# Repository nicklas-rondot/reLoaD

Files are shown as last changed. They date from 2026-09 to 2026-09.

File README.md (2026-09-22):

# *reLoaD* framework

The *reLoaD* (reconfigurable Lab on a Disc) framework is an open-hardware centrifugal microfluidics framework for research, teaching and application. It consists of three core modules:

1. The *Motor* module:
  Consists of a consumer-grade brushless DC (BLDC) motor driven by a PCB with a microcontroller, three-phase half bridge and magnetic encoder using field-oriented-control (FOC). This enables both high-speed rotation for centrifugal microfluidic operations and precise angular positioning for sensor alignment.
2. The *Base* module:
  A stationary PCB with a microcontroller that serves as a platform to mount/control stationary sensors and actuators. Furthermore, it integrates wireless power transmission electronics.
3. The *Spinnner* module:
  A PCB co-rotating with the microfluidic disc with a microcontroller that serves as a platform to mount/control co-rotating sensors and actuators (primarily heaters). It integrates rectification and power regulation electronics for wirelessly receiving power from the *Base* module.

All modules are based on the ESP32-S3 microcontroller. Sensors and actuators can be placed on *Shields*, PCBs that mount to the Base and Spinner modules using standard pin headers. It is advantageous to place optical sensors and actuators on a *Base Shield*, as this allows using the rotation of the microfluidic disc to align multiple chambers with a single sensor one after another. Moreover, it is recommended to place sensors and actuators that need to be in direct contact with the microfluidic disc on the *Spinner Shield*, since this enables interaction with the disc during rotation and necessitates no movable components. The control software is available at github.com/nicklas-rondot/reLoaD-control

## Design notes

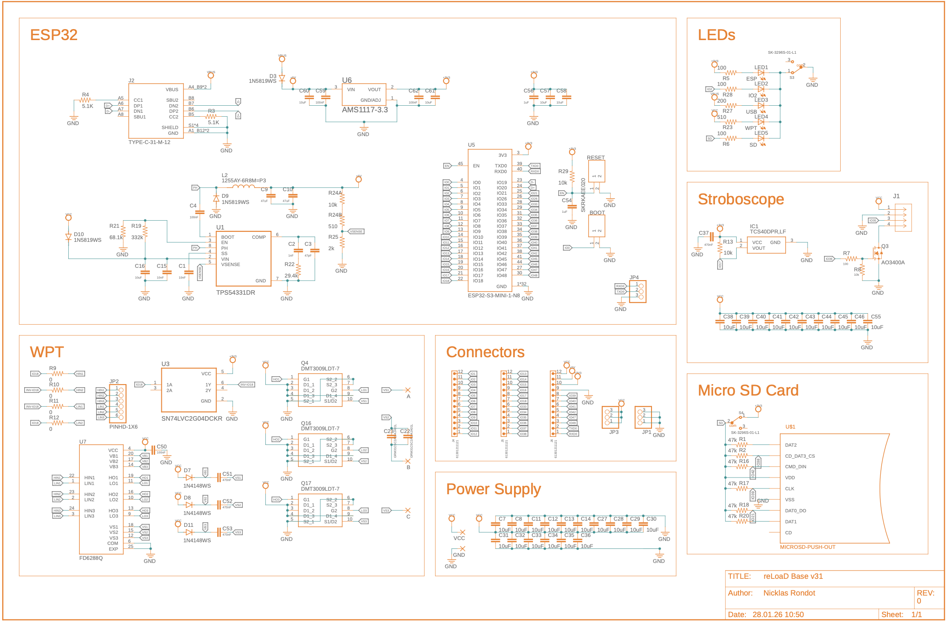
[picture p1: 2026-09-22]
Base/hardware/Base Schematic.png

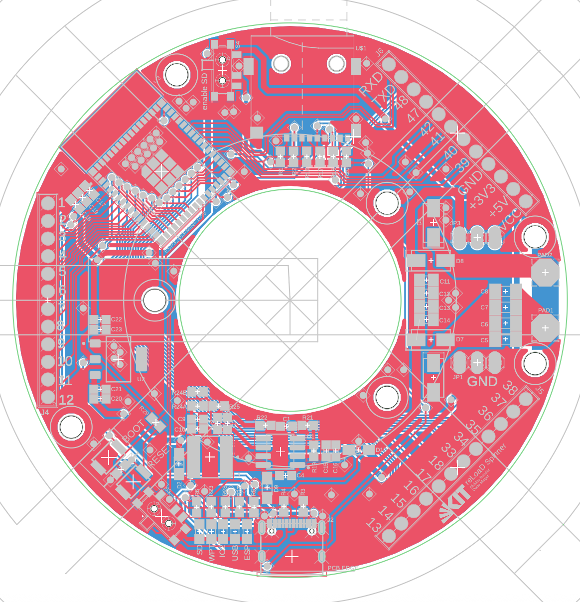
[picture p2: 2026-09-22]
Spinner/hardware/Spinner PCB.png

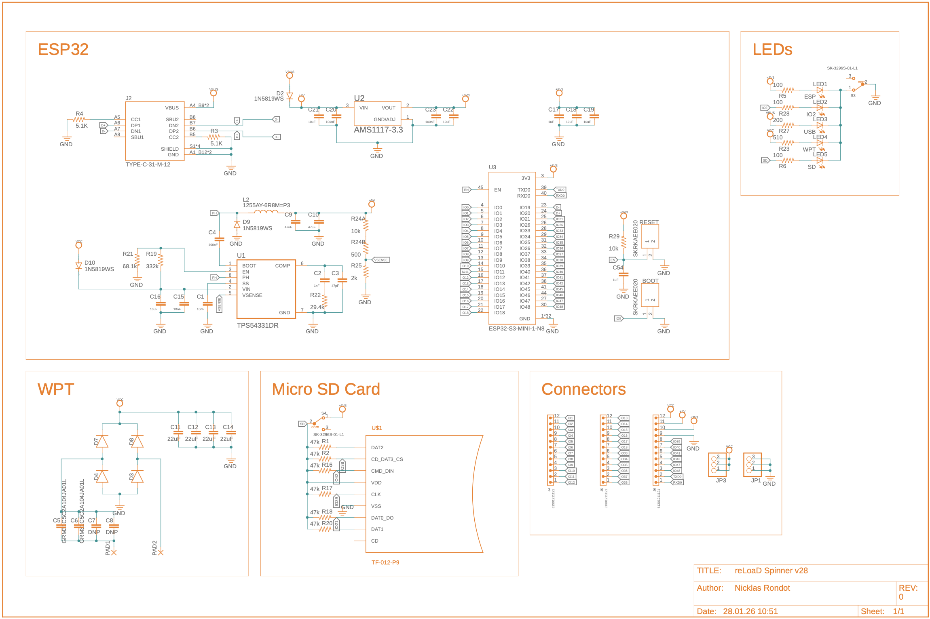
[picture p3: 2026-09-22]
Spinner/hardware/Spinner Schematic.png

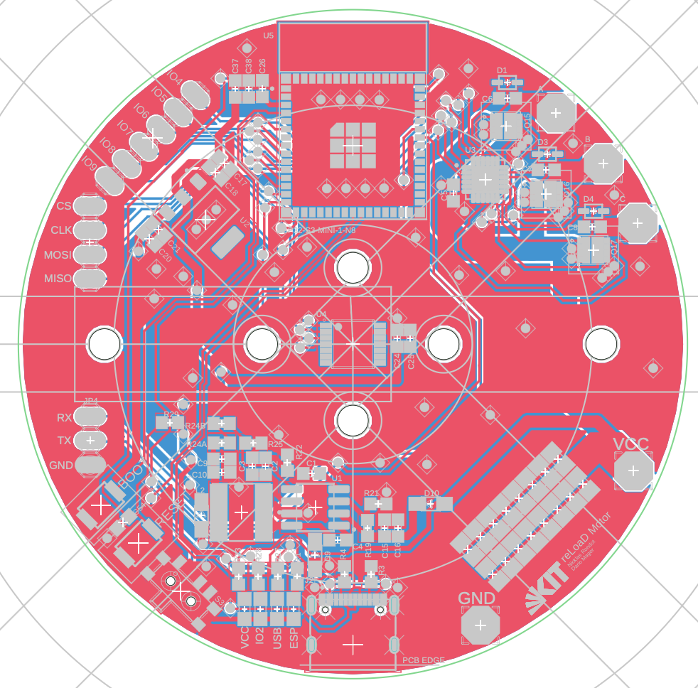
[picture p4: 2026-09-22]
Motor/hardware/Motor PCB.png

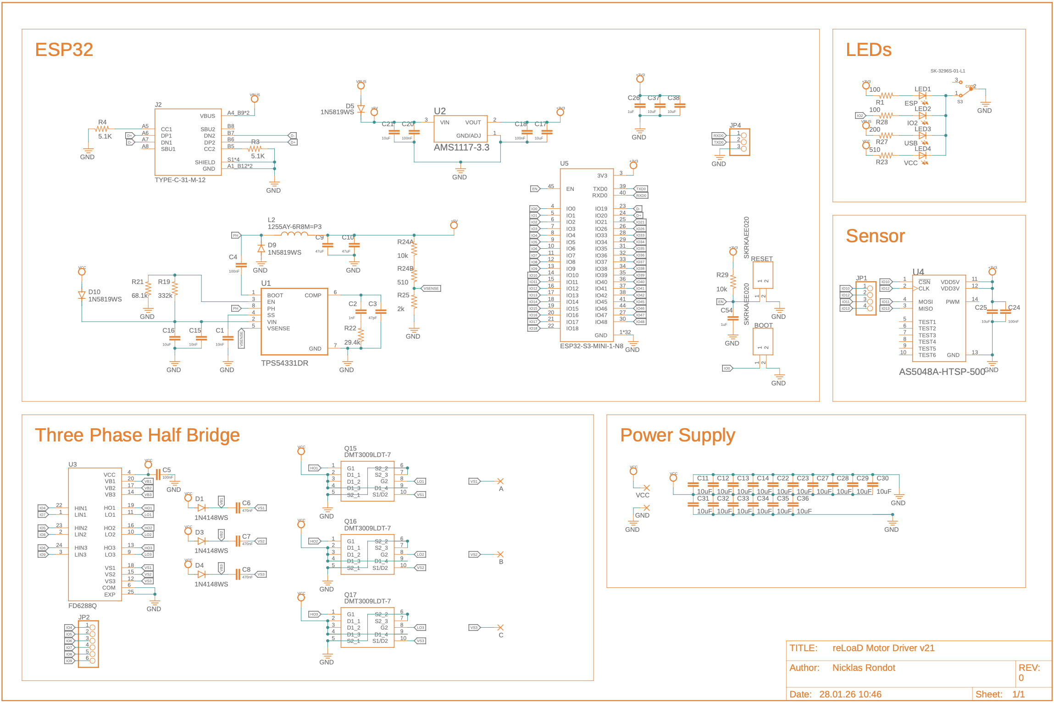
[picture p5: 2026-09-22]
Motor/hardware/Motor Schematic.png

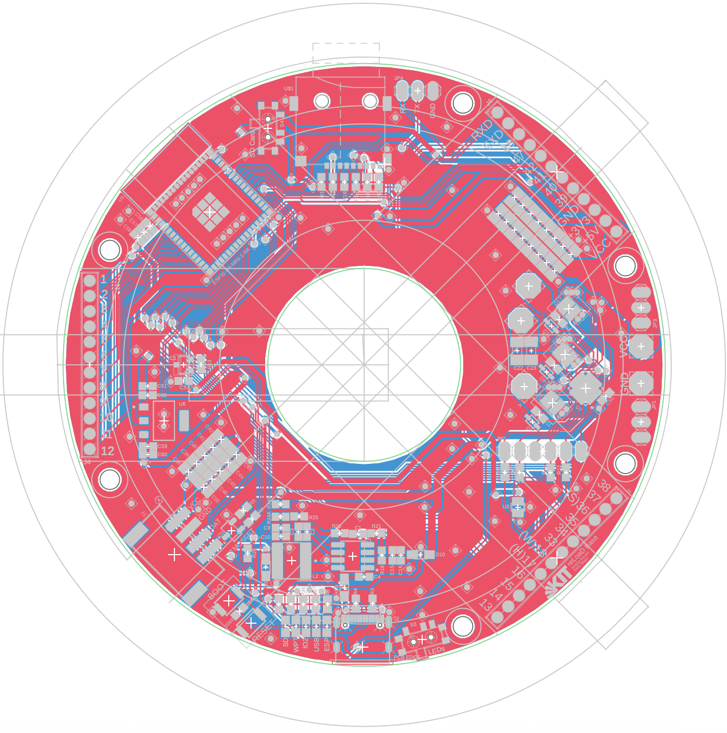
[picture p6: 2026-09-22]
Base/hardware/Base PCB.png

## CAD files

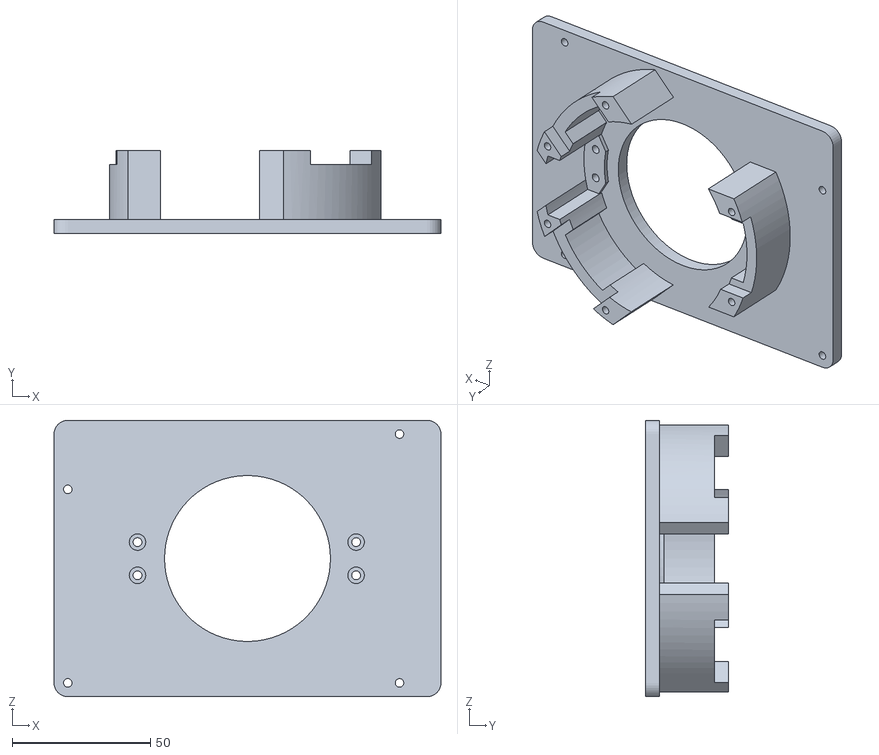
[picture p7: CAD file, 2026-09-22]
assembly/reLoaD Base Mount.stl
140.0 x 30.0 x 100.0

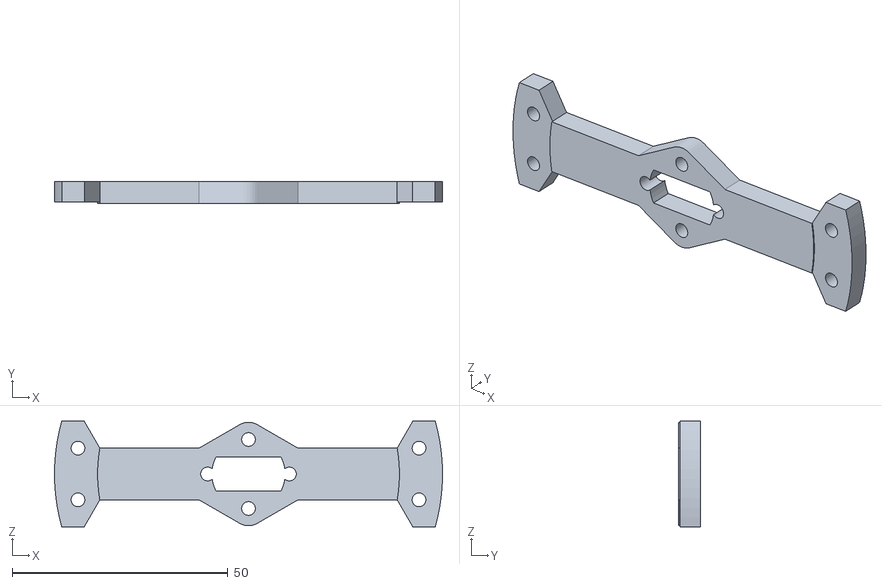
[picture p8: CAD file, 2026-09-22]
assembly/reLoaD Motor Mount high version.stl
90.0 x 5.00 x 24.5

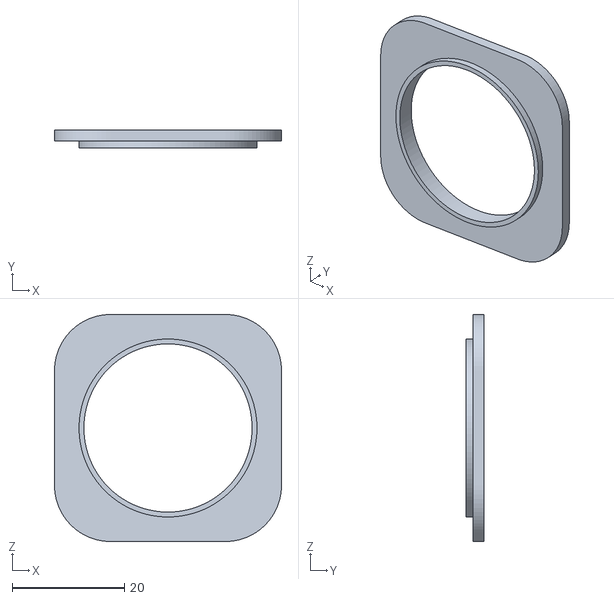
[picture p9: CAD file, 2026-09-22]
assembly/reLoaD Coil lifter v2.stl
40.5 x 3.25 x 40.5

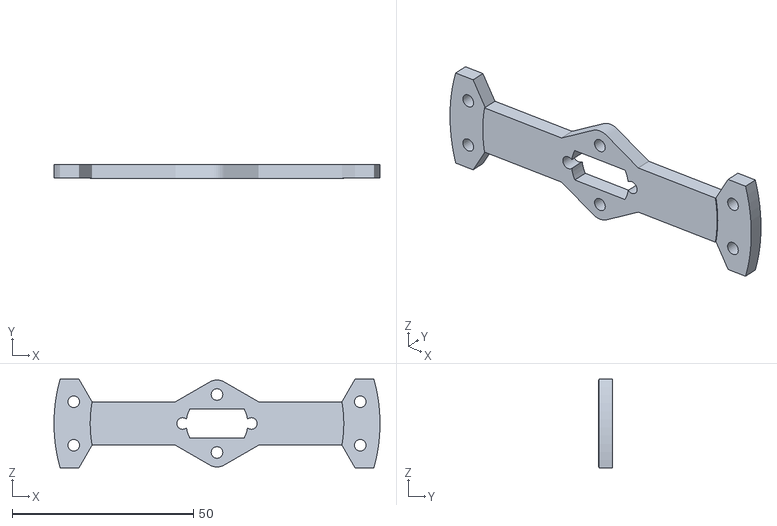
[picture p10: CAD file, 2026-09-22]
assembly/reLoaD Motor Mount.stl
90.0 x 4.00 x 24.5

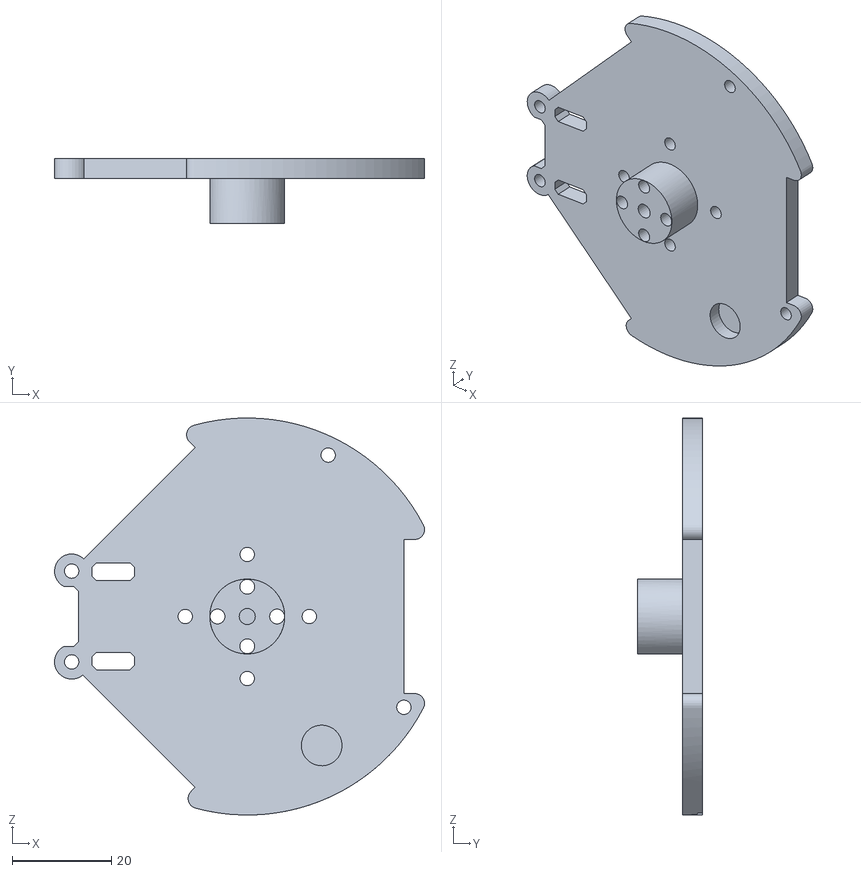
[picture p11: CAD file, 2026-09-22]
assembly/reLoaD Spinner Mount v3.stl
74.6 x 13.0 x 80.0

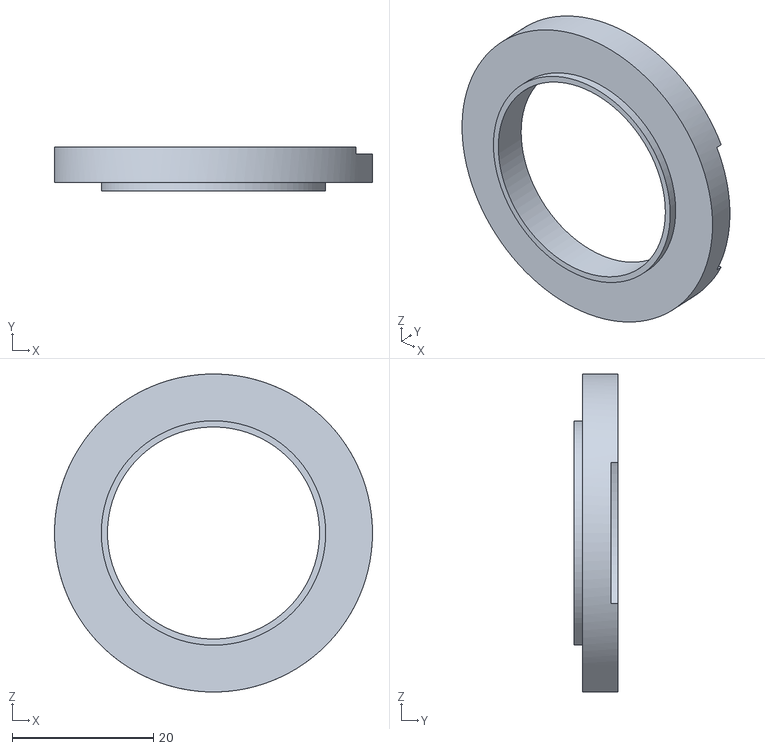
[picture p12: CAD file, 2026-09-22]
assembly/reLoaD Coil lifter.stl
45.0 x 6.25 x 45.0

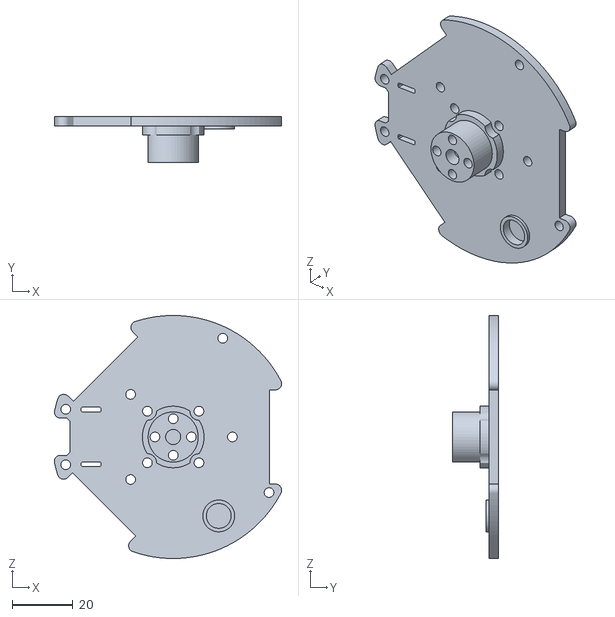
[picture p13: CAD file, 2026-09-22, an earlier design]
assembly/reLoaD Spinner Mount v2.stl
74.9 x 15.0 x 80.0

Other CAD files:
assembly/reLoaD assembly.step

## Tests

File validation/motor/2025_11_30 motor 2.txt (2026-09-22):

11:09:17.006	RPM Sensor Ready (Adaptive Mode)...
RPM:0

11:09:21.838	RPM:12.40

11:09:22.438	RPM:100.68

11:09:22.572	RPM:439.07

11:09:22.692	RPM:480.92

11:09:22.812	RPM:516.97

11:09:22.932	RPM:548.59

11:09:23.037	RPM:576.83

11:09:23.127	RPM:602.31

11:09:23.217	RPM:625.52

11:09:23.322	RPM:646.75

11:09:23.412	RPM:666.37

11:09:23.487	RPM:684.65

11:09:23.577	RPM:701.69

11:09:23.667	RPM:717.77

11:09:23.742	RPM:732.71

11:09:23.831	RPM:746.83

11:09:23.907	RPM:760.03

11:09:23.981	RPM:772.44

11:09:24.056	RPM:784.27

11:09:24.131	RPM:795.50

11:09:24.206	RPM:806.28

11:09:24.282	RPM:816.37

11:09:24.356	RPM:826.13

11:09:24.432	RPM:835.38

11:09:24.492	RPM:844.12

11:09:24.567	RPM:852.47

11:09:24.642	RPM:860.49

11:09:24.702	RPM:868.11

11:09:24.776	RPM:875.25

11:09:24.852	RPM:882.20

11:09:24.910	RPM:888.84

11:09:24.987	RPM:895.09

11:09:25.047	RPM:900.96

11:09:25.107	RPM:906.51

11:09:25.182	RPM:911.69

11:09:25.241	RPM:916.53

11:09:25.302	RPM:921.09

11:09:25.376	RPM:925.41

11:09:25.437	RPM:929.48

11:09:25.496	RPM:933.30

11:09:25.571	RPM:937.03

11:09:25.630	RPM:940.38

11:09:25.692	RPM:943.57

11:09:25.752	RPM:946.43

11:09:25.827	RPM:949.25

11:09:25.887	RPM:951.78

11:09:25.947	RPM:954.26

11:09:26.006	RPM:956.75

11:09:26.066	RPM:958.90

11:09:26.142	RPM:960.98

11:09:26.202	RPM:962.90

11:09:26.261	RPM:964.69

11:09:26.322	RPM:966.37

11:09:26.381	RPM:967.99

11:09:26.442	RPM:969.37

11:09:26.502	RPM:970.81

11:09:26.561	RPM:972.20

11:09:26.636	RPM:973.52

11:09:26.697	RPM:974.72

11:09:26.756	RPM:975.86

11:09:26.817	RPM:976.94

11:09:26.877	RPM:977.84

11:09:26.937	RPM:978.86

11:09:26.996	RPM:979.69

11:09:27.056	RPM:980.58

11:09:27.117	RPM:981.55

11:09:27.177	RPM:982.45

11:09:27.236	RPM:983.16

11:09:27.297	RPM:983.93

11:09:27.371	RPM:984.58

11:09:27.431	RPM:985.35

11:09:27.492	RPM:985.80

11:09:27.552	RPM:986.52

11:09:27.611	RPM:987.23

11:09:27.671	RPM:987.82

11:09:27.731	RPM:988.34

11:09:27.792	RPM:988.86

11:09:27.851	RPM:989.25

11:09:27.912	RPM:989.71

11:09:27.971	RPM:990.10

11:09:28.031	RPM:990.36

11:09:28.092	RPM:990.82

11:09:28.151	RPM:991.21

11:09:28.211	RPM:991.54

11:09:28.271	RPM:992.00

11:09:28.331	RPM:992.33

11:09:28.392	RPM:992.52

11:09:28.452	RPM:992.85

11:09:28.512	RPM:992.98

11:09:28.570	RPM:993.31

11:09:28.631	RPM:993.57

11:09:28.691	RPM:993.90

11:09:28.751	RPM:994.17

11:09:28.811	RPM:994.43

11:09:28.887	RPM:994.69

11:09:28.931	RPM:994.83

11:09:28.992	RPM:994.96

11:09:29.067	RPM:995.22

11:09:29.112	RPM:995.49

11:09:29.187	RPM:995.69

11:09:29.247	RPM:996.02

11:09:29.306	RPM:996.15

11:09:29.366	RPM:996.41

11:09:29.427	RPM:996.41

11:09:29.487	RPM:996.55

11:09:29.546	RPM:996.68

11:09:29.606	RPM:996.74

11:09:29.666	RPM:996.94

11:09:29.726	RPM:997.08

11:09:29.786	RPM:997.14

11:09:29.846	RPM:997.34

11:09:29.906	RPM:997.47

11:09:29.966	RPM:997.47

11:09:30.026	RPM:997.47

11:09:30.087	RPM:997.47

11:09:30.146	RPM:997.54

11:09:30.206	RPM:997.61

11:09:30.266	RPM:997.87

11:09:30.326	RPM:997.94

11:09:30.387	RPM:997.94

11:09:30.446	RPM:997.94

11:09:30.506	RPM:998.07

11:09:30.566	RPM:998.14

11:09:30.626	RPM:998.14

11:09:30.685	RPM:998.27

11:09:30.746	RPM:998.27

11:09:30.806	RPM:998.40

11:09:30.866	RPM:998.47

11:09:30.926	RPM:998.54

11:09:30.987	RPM:998.67

11:09:31.046	RPM:998.73

11:09:31.106	RPM:998.73

11:09:31.166	RPM:998.80

11:09:31.226	RPM:998.87

11:09:31.287	RPM:998.93

11:09:31.346	RPM:999.00

11:09:31.406	RPM:999.00

11:09:31.466	RPM:999.07

11:09:31.526	RPM:999.07

11:09:31.587	RPM:999.07

11:09:31.646	RPM:999.20

11:09:31.706	RPM:999.13

11:09:31.766	RPM:999.33

11:09:31.826	RPM:999.27

11:09:31.887	RPM:999.33

11:09:31.946	RPM:999.27

11:09:32.006	RPM:999.33

11:09:32.066	RPM:999.33

11:09:32.126	RPM:999.47

11:09:32.187	RPM:999.47

11:09:32.246	RPM:999.47

11:09:32.306	RPM:999.47

11:09:32.366	RPM:999.53

11:09:32.426	RPM:999.47

11:09:32.487	RPM:999.40

11:09:32.546	RPM:999.40

11:09:32.606	RPM:999.40

11:09:32.666	RPM:999.40

11:09:32.726	RPM:999.53

11:09:32.786	RPM:999.60

11:09:32.846	RPM:999.60

11:09:32.906	RPM:999.60

11:09:32.966	RPM:999.67

11:09:33.026	RPM:999.53

11:09:33.087	RPM:999.67

11:09:33.146	RPM:999.53

11:09:33.206	RPM:999.47

11:09:33.266	RPM:999.60

11:09:33.326	RPM:999.53

11:09:33.386	RPM:999.53

11:09:33.446	RPM:999.53

11:09:33.506	RPM:999.47

11:09:33.566	RPM:999.53

11:09:33.626	RPM:999.53

11:09:33.687	RPM:999.67

11:09:33.746	RPM:999.67

11:09:33.806	RPM:999.73

11:09:33.866	RPM:999.73

11:09:33.926	RPM:999.73

11:09:33.986	RPM:999.67

11:09:34.046	RPM:999.67

11:09:34.106	RPM:999.73

11:09:34.166	RPM:999.73

11:09:34.226	RPM:999.73

11:09:34.285	RPM:999.87

11:09:34.346	RPM:999.80

11:09:34.406	RPM:999.73

11:09:34.465	RPM:999.87

11:09:34.526	RPM:999.80

11:09:34.586	RPM:999.93

11:09:34.645	RPM:999.87

11:09:34.706	RPM:1000.00

11:09:34.766	RPM:1000.00

11:09:34.826	RPM:1000.00

11:09:34.886	RPM:999.93

11:09:34.946	RPM:999.93

11:09:35.005	RPM:999.87

11:09:35.066	RPM:999.87

11:09:35.126	RPM:999.93

11:09:35.186	RPM:999.93

11:09:35.246	RPM:1000.00

11:09:35.306	RPM:1000.00

11:09:35.366	RPM:1000.00

11:09:35.426	RPM:999.93

11:09:35.486	RPM:999.93

11:09:35.546	RPM:999.93

11:09:35.606	RPM:1000.00

11:09:35.666	RPM:1000.00

11:09:35.726	RPM:1000.00

11:09:35.785	RPM:1000.00

11:09:35.846	RPM:1000.13

11:09:35.906	RPM:1002.47

11:09:35.966	RPM:1009.01

11:09:36.026	RPM:1017.16

11:09:36.086	RPM:1026.55

11:09:36.146	RPM:1036.70

11:09:36.206	RPM:1047.63

11:09:36.251	RPM:1058.87

11:09:36.311	RPM:1070.43

11:09:36.371	RPM:1082.17

11:09:36.416	RPM:1093.61

11:09:36.476	RPM:1105.14

11:09:36.536	RPM:1116.49

11:09:36.581	RPM:1127.40

11:09:36.626	RPM:1138.00

11:09:36.686	RPM:1148.37

11:09:36.746	RPM:1158.48

11:09:36.791	RPM:1168.32

11:09:36.836	RPM:1177.67

11:09:36.896	RPM:1186.80

11:09:36.941	RPM:1195.60

11:09:36.986	RPM:1204.24

11:09:37.046	RPM:1212.32

11:09:37.090	RPM:1220.31

11:09:37.136	RPM:1227.90

11:09:37.181	RPM:1235.28

11:09:37.240	RPM:1242.24

11:09:37.286	RPM:1249.06

11:09:37.331	RPM:1255.65

11:09:37.376	RPM:1261.88

11:09:37.421	RPM:1267.96

11:09:37.466	RPM:1273.89

11:09:37.526	RPM:1279.43

11:09:37.571	RPM:1285.13

11:09:37.616	RPM:1290.21

11:09:37.660	RPM:1295.56

11:09:37.706	RPM:1300.39

11:09:37.751	RPM:1305.48

11:09:37.796	RPM:1309.81

11:09:37.841	RPM:1314.29

11:09:37.886	RPM:1318.68

11:09:37.931	RPM:1322.63

11:09:37.976	RPM:1327.08

11:09:38.021	RPM:1331.09

11:09:38.065	RPM:1334.76

11:09:38.111	RPM:1338.45

11:09:38.156	RPM:1342.28

11:09:38.201	RPM:1345.77

11:09:38.246	RPM:1349.04

11:09:38.291	RPM:1352.33

11:09:38.336	RPM:1355.38

11:09:38.381	RPM:1358.70

11:09:38.426	RPM:1361.53

11:09:38.471	RPM:1364.50

11:09:38.516	RPM:1367.49

11:09:38.561	RPM:1370.24

11:09:38.606	RPM:1372.87

11:09:38.651	RPM:1375.52

11:09:38.696	RPM:1378.04

11:09:38.724	RPM:1380.58

11:09:38.771	RPM:1383.13

11:09:38.816	RPM:1385.68

11:09:38.861	RPM:1387.86

11:09:38.906	RPM:1389.79

11:09:38.951	RPM:1392.37

11:09:38.996	RPM:1394.31

11:09:39.041	RPM:1396.65

11:09:39.086	RPM:1398.86

11:09:39.114	RPM:1400.95

11:09:39.161	RPM:1403.18

11:09:39.205	RPM:1405.15

11:09:39.251	RPM:1406.73

11:09:39.296	RPM:1408.72

11:09:39.325	RPM:1410.57

11:09:39.371	RPM:1412.43

11:09:39.416	RPM:1413.89

11:09:39.461	RPM:1415.76

11:09:39.506	RPM:1417.37

11:09:39.551	RPM:1418.98

11:09:39.580	RPM:1420.32

11:09:39.626	RPM:1421.80

11:09:39.671	RPM:1423.15

11:09:39.716	RPM:1424.77

11:09:39.761	RPM:1426.26

11:09:39.805	RPM:1427.35

11:09:39.833	RPM:1428.98

11:09:39.881	RPM:1430.07

11:09:39.926	RPM:1431.71

11:09:39.971	RPM:1432.80

11:09:40.000	RPM:1434.17

11:09:40.046	RPM:1435.27

11:09:40.091	RPM:1436.64

11:09:40.135	RPM:1437.75

11:09:40.181	RPM:1439.13

11:09:40.210	RPM:1440.51

11:09:40.256	RPM:1441.61

11:09:40.300	RPM:1442.59

11:09:40.346	RPM:1443.70

11:09:40.373	RPM:1444.81

11:09:40.421	RPM:1445.64

11:09:40.466	RPM:1446.62

11:09:40.511	RPM:1447.60

11:09:40.556	RPM:1448.44

11:09:40.584	RPM:1449.56

11:09:40.631	RPM:1450.82

11:09:40.676	RPM:1451.66

11:09:40.705	RPM:1452.50

11:09:40.751	RPM:1453.49

11:09:40.796	RPM:1454.19

11:09:40.841	RPM:1455.18

11:09:40.870	RPM:1455.89

11:09:40.916	RPM:1456.45

11:09:40.961	RPM:1457.58

11:09:41.005	RPM:1458.43

11:09:41.051	RPM:1459.14

11:09:41.078	RPM:1459.71

11:09:41.126	RPM:1460.56

11:09:41.171	RPM:1461.13

11:09:41.216	RPM:1461.85

11:09:41.243	RPM:1462.42

11:09:41.290	RPM:1462.99

11:09:41.336	RPM:1463.70

11:09:41.365	RPM:1464.56

11:09:41.411	RPM:1464.99

11:09:41.456	RPM:1465.56

11:09:41.501	RPM:1466.28

11:09:41.528	RPM:1466.99

11:09:41.576	RPM:1467.42

11:09:41.621	RPM:1467.85

11:09:41.666	RPM:1468.43

11:09:41.693	RPM:1469.00

11:09:41.740	RPM:1469.58

11:09:41.786	RPM:1470.44

11:09:41.815	RPM:1470.73

11:09:41.861	RPM:1471.17

11:09:41.906	RPM:1471.74

11:09:41.935	RPM:1472.32

11:09:41.981	RPM:1472.61

11:09:42.026	RPM:1473.04

11:09:42.071	RPM:1473.77

11:09:42.097	RPM:1474.20

11:09:42.146	RPM:1474.49

11:09:42.191	RPM:1474.93

11:09:42.235	RPM:1475.80

11:09:42.262	RPM:1476.23

11:09:42.311	RPM:1476.67

11:09:42.356	RPM:1476.81

11:09:42.385	RPM:1477.54

11:09:42.431	RPM:1477.83

11:09:42.476	RPM:1478.12

11:09:42.505	RPM:1478.42

11:09:42.551	RPM:1478.71

11:09:42.596	RPM:1479.14

11:09:42.641	RPM:1479.58

11:09:42.668	RPM:1480.17

11:09:42.715	RPM:1480.46

11:09:42.761	RPM:1480.75

11:09:42.790	RPM:1481.19

11:09:42.836	RPM:1481.34

11:09:42.881	RPM:1481.63

11:09:42.910	RPM:1482.07

11:09:42.956	RPM:1482.51

11:09:43.001	RPM:1482.80

11:09:43.046	RPM:1483.09

11:09:43.073	RPM:1483.24

11:09:43.121	RPM:1483.39

11:09:43.166	RPM:1484.12

11:09:43.195	RPM:1484.27

11:09:43.241	RPM:1484.41

11:09:43.286	RPM:1484.56

11:09:43.315	RPM:1484.85

11:09:43.361	RPM:1485.15

11:09:43.405	RPM:1485.44

11:09:43.450	RPM:1485.74

11:09:43.480	RPM:1485.88

11:09:43.525	RPM:1486.18

11:09:43.571	RPM:1486.47

11:09:43.597	RPM:1486.47

11:09:43.646	RPM:1486.77

11:09:43.691	RPM:1486.77

11:09:43.720	RPM:1487.21

11:09:43.766	RPM:1487.36

11:09:43.811	RPM:1487.80

11:09:43.840	RPM:1487.95

11:09:43.886	RPM:1487.95

11:09:43.931	RPM:1488.24

11:09:43.975	RPM:1488.54

11:09:44.003	RPM:1488.69

11:09:44.050	RPM:1488.98

11:09:44.080	RPM:1489.13

11:09:44.125	RPM:1489.28

11:09:44.171	RPM:1489.28

11:09:44.216	RPM:1489.57

11:09:44.244	RPM:1489.72

11:09:44.291	RPM:1489.87

11:09:44.336	RPM:1490.02

11:09:44.364	RPM:1490.46

11:09:44.410	RPM:1490.61

11:09:44.455	RPM:1490.91

11:09:44.501	RPM:1490.91

11:09:44.529	RPM:1491.20

11:09:44.575	RPM:1491.50

11:09:44.605	RPM:1491.65

11:09:44.650	RPM:1491.80

11:09:44.696	RPM:1491.94

11:09:44.740	RPM:1492.09

11:09:44.767	RPM:1492.24

11:09:44.816	RPM:1492.09

11:09:44.861	RPM:1492.24

11:09:44.888	RPM:1492.39

11:09:44.936	RPM:1492.54

11:09:44.965	RPM:1492.98

11:09:45.011	RPM:1492.98

11:09:45.056	RPM:1493.43

11:09:45.100	RPM:1493.58

11:09:45.130	RPM:1493.88

11:09:45.175	RPM:1493.73

11:09:45.221	RPM:1494.02

11:09:45.248	RPM:1494.32

11:09:45.296	RPM:1494.32

11:09:45.341	RPM:1494.02

11:09:45.367	RPM:1494.32

11:09:45.416	RPM:1494.47

11:09:45.461	RPM:1494.32

11:09:45.490	RPM:1494.17

11:09:45.536	RPM:1494.32

11:09:45.581	RPM:1494.47

11:09:45.608	RPM:1494.47

11:09:45.656	RPM:1494.62

11:09:45.699	RPM:1494.77

11:09:45.731	RPM:1494.92

11:09:45.775	RPM:1494.92

11:09:45.820	RPM:1495.07

11:09:45.850	RPM:1495.36

11:09:45.896	RPM:1495.66

11:09:45.941	RPM:1495.51

11:09:45.967	RPM:1495.66

11:09:46.016	RPM:1495.36

11:09:46.061	RPM:1495.36

11:09:46.106	RPM:1495.51

11:09:46.133	RPM:1495.66

11:09:46.180	RPM:1495.81

11:09:46.210	RPM:1495.51

11:09:46.256	RPM:1495.51

11:09:46.300	RPM:1495.66

11:09:46.346	RPM:1495.81

11:09:46.373	RPM:1495.96

11:09:46.421	RPM:1495.81

11:09:46.466	RPM:1495.96

11:09:46.493	RPM:1496.26

11:09:46.541	RPM:1496.41

11:09:46.570	RPM:1496.26

11:09:46.616	RPM:1496.26

11:09:46.660	RPM:1496.11

11:09:46.706	RPM:1496.41

11:09:46.735	RPM:1496.56

11:09:46.781	RPM:1496.86

11:09:46.825	RPM:1496.71

11:09:46.855	RPM:1496.86

11:09:46.901	RPM:1497.01

11:09:46.946	RPM:1497.01

11:09:46.972	RPM:1496.86

11:09:47.020	RPM:1497.16

11:09:47.066	RPM:1497.30

11:09:47.095	RPM:1497.45

11:09:47.141	RPM:1497.45

11:09:47.186	RPM:1497.60

11:09:47.215	RPM:1497.60

11:09:47.260	RPM:1497.45

11:09:47.306	RPM:1497.30

11:09:47.332	RPM:1497.45

11:09:47.380	RPM:1497.45

11:09:47.425	RPM:1497.45

11:09:47.455	RPM:1497.30

11:09:47.500	RPM:1497.45

11:09:47.546	RPM:1497.60

11:09:47.575	RPM:1497.45

11:09:47.621	RPM:1497.75

11:09:47.666	RPM:1497.60

11:09:47.693	RPM:1497.60

11:09:47.740	RPM:1497.90

11:09:47.786	RPM:1497.75

11:09:47.831	RPM:1497.60

11:09:47.856	RPM:1497.45

11:09:47.906	RPM:1497.45

11:09:47.935	RPM:1497.45

11:09:47.981	RPM:1497.60

11:09:48.025	RPM:1497.60

11:09:48.055	RPM:1497.75

11:09:48.101	RPM:1498.05

11:09:48.146	RPM:1498.35

11:09:48.191	RPM:1498.35

11:09:48.219	RPM:1498.20

11:09:48.266	RPM:1498.35

11:09:48.295	RPM:1498.50

11:09:48.341	RPM:1498.50

11:09:48.386	RPM:1498.20

11:09:48.415	RPM:1498.35

11:09:48.461	RPM:1498.35

11:09:48.506	RPM:1498.35

11:09:48.550	RPM:1498.50

11:09:48.577	RPM:1498.65

11:09:48.625	RPM:1498.65

11:09:48.655	RPM:1498.20

11:09:48.701	RPM:1498.65

11:09:48.746	RPM:1498.50

11:09:48.775	RPM:1498.35

11:09:48.821	RPM:1498.50

11:09:48.866	RPM:1498.65

11:09:48.911	RPM:1498.95

11:09:48.938	RPM:1498.95

11:09:48.986	RPM:1498.65

11:09:49.031	RPM:1498.50

11:09:49.058	RPM:1498.65

11:09:49.106	RPM:1498.35

11:09:49.135	RPM:1498.50

11:09:49.181	RPM:1498.80

11:09:49.224	RPM:1499.10

11:09:49.270	RPM:1498.95

11:09:49.297	RPM:1499.10

11:09:49.346	RPM:1499.10

11:09:49.391	RPM:1499.10

11:09:49.419	RPM:1499.25

11:09:49.466	RPM:1499.25

11:09:49.495	RPM:1498.95

11:09:49.541	RPM:1498.95

11:09:49.586	RPM:1499.10

11:09:49.631	RPM:1498.95

11:09:49.657	RPM:1498.80

11:09:49.706	RPM:1498.80

11:09:49.750	RPM:1498.80

11:09:49.777	RPM:1498.95

11:09:49.825	RPM:1498.95

11:09:49.855	RPM:1498.95

11:09:49.901	RPM:1498.80

11:09:49.946	RPM:1498.80

11:09:49.991	RPM:1499.10

11:09:50.018	RPM:1499.25

11:09:50.066	RPM:1499.40

11:09:50.111	RPM:1499.40

11:09:50.137	RPM:1499.55

11:09:50.186	RPM:1499.40

11:09:50.231	RPM:1499.25

11:09:50.257	RPM:1499.25

11:09:50.306	RPM:1499.10

11:09:50.350	RPM:1498.80

11:09:50.376	RPM:1498.80

11:09:50.425	RPM:1498.95

11:09:50.470	RPM:1499.25

11:09:50.500	RPM:1499.25

11:09:50.546	RPM:1499.40

11:09:50.590	RPM:1499.40

11:09:50.617	RPM:1499.55

11:09:50.666	RPM:1499.40

11:09:50.695	RPM:1499.25

11:09:50.741	RPM:1499.10

11:09:50.786	RPM:1499.40

11:09:50.831	RPM:1499.40

11:09:50.860	RPM:1499.55

11:09:50.906	RPM:1499.40

11:09:50.950	RPM:1499.40

11:09:50.977	RPM:1499.55

11:09:51.025	RPM:1499.70

11:09:51.055	RPM:1499.55

11:09:51.101	RPM:1499.55

11:09:51.146	RPM:1499.40

11:09:51.191	RPM:1499.40

11:09:51.219	RPM:1499.40

11:09:51.266	RPM:1499.40

11:09:51.311	RPM:1499.55

11:09:51.338	RPM:1499.55

11:09:51.386	RPM:1499.85

11:09:51.431	RPM:1499.70

11:09:51.457	RPM:1499.85

11:09:51.506	RPM:1499.85

11:09:51.550	RPM:1500.00

11:09:51.577	RPM:1500.15

11:09:51.625	RPM:1500.00

11:09:51.670	RPM:1500.15

11:09:51.700	RPM:1499.85

11:09:51.746	RPM:1500.00

11:09:51.790	RPM:1500.00

11:09:51.817	RPM:1499.70

11:09:51.866	RPM:1500.00

11:09:51.910	RPM:1499.85

11:09:51.937	RPM:1499.55

11:09:51.986	RPM:1499.55

11:09:52.031	RPM:1499.55

11:09:52.060	RPM:1499.40

11:09:52.106	RPM:1499.40

11:09:52.149	RPM:1499.55

11:09:52.179	RPM:1499.70

11:09:52.224	RPM:1499.85

11:09:52.255	RPM:1499.85

11:09:52.300	RPM:1499.85

11:09:52.345	RPM:1499.85

11:09:52.390	RPM:1499.85

11:09:52.417	RPM:1499.55

11:09:52.465	RPM:1499.55

11:09:52.510	RPM:1499.40

11:09:52.540	RPM:1499.55

11:09:52.586	RPM:1499.70

11:09:52.631	RPM:1499.70

11:09:52.657	RPM:1499.70

11:09:52.706	RPM:1499.70

11:09:52.750	RPM:1500.00

11:09:52.777	RPM:1500.15

11:09:52.825	RPM:1499.85

11:09:52.870	RPM:1500.00

11:09:52.900	RPM:1500.00

11:09:52.946	RPM:1500.30

11:09:52.991	RPM:1500.30

11:09:53.018	RPM:1500.15

11:09:53.066	RPM:1500.15

11:09:53.111	RPM:1500.00

11:09:53.139	RPM:1500.00

11:09:53.186	RPM:1499.85

11:09:53.231	RPM:1499.85

11:09:53.260	RPM:1499.85

11:09:53.306	RPM:1499.85

11:09:53.350	RPM:1500.00

11:09:53.380	RPM:1500.00

11:09:53.425	RPM:1500.00

11:09:53.455	RPM:1499.85

11:09:53.501	RPM:1500.00

11:09:53.546	RPM:1500.15

11:09:53.591	RPM:1500.15

11:09:53.618	RPM:1500.15

11:09:53.666	RPM:1500.00

11:09:53.710	RPM:1499.85

11:09:53.740	RPM:1499.85

11:09:53.786	RPM:1499.70

11:09:53.831	RPM:1499.70

11:09:53.856	RPM:1499.70

11:09:53.906	RPM:1499.55

11:09:53.950	RPM:1499.70

11:09:53.977	RPM:1499.55

11:09:54.025	RPM:1499.70

11:09:54.070	RPM:1499.55

11:09:54.100	RPM:1499.85

11:09:54.145	RPM:1500.00

11:09:54.191	RPM:1500.00

11:09:54.218	RPM:1500.30

11:09:54.266	RPM:1500.15

11:09:54.311	RPM:1500.15

11:09:54.338	RPM:1500.00

11:09:54.386	RPM:1500.15

11:09:54.431	RPM:1500.15

11:09:54.460	RPM:1500.00

11:09:54.506	RPM:1500.00

11:09:54.550	RPM:1500.00

11:09:54.580	RPM:1500.15

11:09:54.625	RPM:1499.85

11:09:54.670	RPM:1499.70

11:09:54.697	RPM:1499.85

11:09:54.746	RPM:1499.85

11:09:54.791	RPM:1499.85

11:09:54.820	RPM:1500.15

11:09:54.866	RPM:1500.00

11:09:54.911	RPM:1500.00

11:09:54.940	RPM:1500.00

11:09:54.986	RPM:1499.85

11:09:55.031	RPM:1499.85

11:09:55.056	RPM:1499.70

11:09:55.106	RPM:1499.40

11:09:55.150	RPM:1499.70

11:09:55.176	RPM:1499.55

11:09:55.224	RPM:1499.40

11:09:55.270	RPM:1499.55

11:09:55.300	RPM:1499.70

11:09:55.345	RPM:1499.85

11:09:55.391	RPM:1499.85

11:09:55.418	RPM:1500.00

11:09:55.466	RPM:1500.00

11:09:55.511	RPM:1500.30

11:09:55.538	RPM:1500.15

11:09:55.586	RPM:1500.00

11:09:55.631	RPM:1500.15

11:09:55.660	RPM:1500.00

11:09:55.705	RPM:1500.00

11:09:55.750	RPM:1499.85

11:09:55.780	RPM:1499.70

11:09:55.825	RPM:1499.55

11:09:55.870	RPM:1499.70

11:09:55.897	RPM:1499.70

11:09:55.946	RPM:1499.55

11:09:55.991	RPM:1499.40

11:09:56.020	RPM:1499.40

11:09:56.066	RPM:1499.25

11:09:56.111	RPM:1499.10

11:09:56.140	RPM:1499.25

11:09:56.186	RPM:1499.40

11:09:56.231	RPM:1499.10

11:09:56.257	RPM:1499.40

11:09:56.306	RPM:1503.91

11:09:56.351	RPM:1509.36

11:09:56.378	RPM:1515.00

11:09:56.425	RPM:1520.99

11:09:56.455	RPM:1527.34

11:09:56.501	RPM:1534.06

11:09:56.545	RPM:1540.67

11:09:56.572	RPM:1547.19

11:09:56.621	RPM:1553.76

11:09:56.650	RPM:1560.22

11:09:56.696	RPM:1566.58

11:09:56.741	RPM:1573.32

11:09:56.767	RPM:1579.78

11:09:56.816	RPM:1585.79

11:09:56.843	RPM:1592.36

11:09:56.875	RPM:1598.64

11:09:56.921	RPM:1604.62

11:09:56.966	RPM:1610.65

11:09:56.992	RPM:1616.03

11:09:57.041	RPM:1621.45

11:09:57.067	RPM:1627.07

11:09:57.116	RPM:1632.56

11:09:57.143	RPM:1637.91

11:09:57.175	RPM:1643.48

11:09:57.221	RPM:1648.53

11:09:57.247	RPM:1653.80

11:09:57.296	RPM:1658.56

11:09:57.322	RPM:1663.34

11:09:57.356	RPM:1668.15

11:09:57.400	RPM:1672.80

11:09:57.426	RPM:1676.91

11:09:57.475	RPM:1681.24

11:09:57.502	RPM:1685.58

11:09:57.536	RPM:1689.76

11:09:57.581	RPM:1694.34

11:09:57.607	RPM:1698.56

11:09:57.641	RPM:1702.03

11:09:57.686	RPM:1706.29

11:09:57.712	RPM:1710.18

11:09:57.745	RPM:1714.29

11:09:57.791	RPM:1718.02

11:09:57.818	RPM:1721.57

11:09:57.850	RPM:1725.53

11:09:57.895	RPM:1729.11

11:09:57.921	RPM:1732.90

11:09:57.954	RPM:1736.11

11:09:57.985	RPM:1739.33

11:09:58.031	RPM:1742.97

11:09:58.057	RPM:1746.22

11:09:58.091	RPM:1749.48

11:09:58.135	RPM:1752.75

11:09:58.161	RPM:1755.82

11:09:58.194	RPM:1759.12

11:09:58.241	RPM:1761.60

11:09:58.267	RPM:1764.29

11:09:58.292	RPM:1767.20

11:09:58.331	RPM:1770.54

11:09:58.375	RPM:1773.47

11:09:58.402	RPM:1775.99

11:09:58.436	RPM:1778.73

11:09:58.464	RPM:1781.26

11:09:58.511	RPM:1784.02

11:09:58.537	RPM:1786.14

11:09:58.563	RPM:1788.70

11:09:58.601	RPM:1791.47

11:09:58.630	RPM:1793.83

11:09:58.675	RPM:1796.19

11:09:58.703	RPM:1798.99

11:09:58.736	RPM:1801.37

11:09:58.764	RPM:1803.75

11:09:58.811	RPM:1806.36

11:09:58.837	RPM:1808.32

11:09:58.861	RPM:1810.28

11:09:58.900	RPM:1812.91

11:09:58.927	RPM:1815.54

11:09:58.975	RPM:1817.74

11:09:59.003	RPM:1819.51

11:09:59.036	RPM:1821.27

11:09:59.064	RPM:1823.04

11:09:59.095	RPM:1825.26

11:09:59.141	RPM:1827.26

11:09:59.168	RPM:1829.49

11:09:59.200	RPM:1831.05

11:09:59.230	RPM:1833.07

11:09:59.260	RPM:1834.64

11:09:59.306	RPM:1836.66

11:09:59.333	RPM:1838.46

11:09:59.357	RPM:1840.49

11:09:59.394	RPM:1842.53

11:09:59.420	RPM:1844.11

11:09:59.456	RPM:1845.70

11:09:59.485	RPM:1847.52

11:09:59.531	RPM:1849.34

11:09:59.556	RPM:1851.39

11:09:59.590	RPM:1852.77

11:09:59.616	RPM:1854.60

11:09:59.651	RPM:1855.98

11:09:59.696	RPM:1857.82

11:09:59.722	RPM:1859.43

11:09:59.748	RPM:1860.81

11:09:59.786	RPM:1862.43

11:09:59.812	RPM:1863.59

11:09:59.846	RPM:1864.98

11:09:59.875	RPM:1866.37

11:09:59.921	RPM:1868.23

11:09:59.947	RPM:1869.86

11:09:59.972	RPM:1871.72

11:10:00.010	RPM:1873.36

11:10:00.036	RPM:1874.30

11:10:00.070	RPM:1875.23

11:10:00.100	RPM:1876.88

11:10:00.146	RPM:1878.29

11:10:00.172	RPM:1879.46

11:10:00.197	RPM:1880.64

11:10:00.234	RPM:1882.06

11:10:00.259	RPM:1883.24

11:10:00.296	RPM:1884.42

11:10:00.321	RPM:1885.61

11:10:00.356	RPM:1887.27

11:10:00.400	RPM:1888.22

11:10:00.427	RPM:1889.41

11:10:00.451	RPM:1890.12

11:10:00.490	RPM:1891.07

11:10:00.515	RPM:1892.74

11:10:00.551	RPM:1893.70

11:10:00.576	RPM:1895.38

11:10:00.611	RPM:1896.57

11:10:00.640	RPM:1897.53

11:10:00.670	RPM:1898.73

11:10:00.716	RPM:1899.46

11:10:00.742	RPM:1900.90

11:10:00.766	RPM:1901.38

11:10:00.805	RPM:1902.35

11:10:00.830	RPM:1903.31

11:10:00.866	RPM:1904.52

11:10:00.892	RPM:1905.49

11:10:00.925	RPM:1906.70

11:10:00.955	RPM:1907.43

11:10:00.985	RPM:1908.64

11:10:01.031	RPM:1909.85

11:10:01.056	RPM:1910.83

11:10:01.080	RPM:1911.56

11:10:01.121	RPM:1912.53

11:10:01.147	RPM:1913.51

11:10:01.180	RPM:1914.49

11:10:01.205	RPM:1915.22

11:10:01.241	RPM:1916.20

11:10:01.266	RPM:1916.93

11:10:01.300	RPM:1917.67

11:10:01.330	RPM:1918.40

11:10:01.360	RPM:1919.39

11:10:01.404	RPM:1920.12

11:10:01.430	RPM:1920.86

11:10:01.455	RPM:1921.84

11:10:01.495	RPM:1922.58

11:10:01.520	RPM:1923.32

11:10:01.556	RPM:1924.06

11:10:01.581	RPM:1925.05

11:10:01.616	RPM:1925.55

11:10:01.645	RPM:1926.29

11:10:01.675	RPM:1927.53

11:10:01.705	RPM:1928.76

11:10:01.735	RPM:1929.51

11:10:01.781	RPM:1930.25

11:10:01.806	RPM:1930.75

11:10:01.831	RPM:1931.25

11:10:01.870	RPM:1931.75

11:10:01.895	RPM:1932.49

11:10:01.931	RPM:1933.24

11:10:01.955	RPM:1933.99

11:10:01.991	RPM:1934.49

11:10:02.016	RPM:1934.98

11:10:02.050	RPM:1934.98

11:10:02.076	RPM:1935.48

11:10:02.111	RPM:1936.73

11:10:02.140	RPM:1937.23

11:10:02.170	RPM:1938.23

11:10:02.200	RPM:1938.74

11:10:02.246	RPM:1939.24

11:10:02.272	RPM:1939.49

11:10:02.296	RPM:1940.49

11:10:02.336	RPM:1940.99

11:10:02.361	RPM:1941.75

11:10:02.385	RPM:1942.25

11:10:02.425	RPM:1943.01

11:10:02.450	RPM:1943.51

11:10:02.486	RPM:1944.26

11:10:02.511	RPM:1944.77

11:10:02.546	RPM:1945.53

11:10:02.575	RPM:1946.28

11:10:02.605	RPM:1946.79

11:10:02.635	RPM:1946.79

11:10:02.664	RPM:1947.55

11:10:02.711	RPM:1948.05

11:10:02.737	RPM:1948.56

11:10:02.761	RPM:1949.32

11:10:02.787	RPM:1949.57

11:10:02.831	RPM:1950.33

11:10:02.856	RPM:1950.84

11:10:02.881	RPM:1951.09

11:10:02.921	RPM:1951.60

11:10:02.946	RPM:1952.36

11:10:02.970	RPM:1952.62

11:10:03.011	RPM:1953.13

11:10:03.036	RPM:1953.38

11:10:03.070	RPM:1953.63

11:10:03.096	RPM:1954.40

11:10:03.131	RPM:1955.16

11:10:03.156	RPM:1955.16

11:10:03.191	RPM:1955.93

11:10:03.216	RPM:1956.69

11:10:03.250	RPM:1956.95

11:10:03.279	RPM:1957.46

11:10:03.310	RPM:1957.97

11:10:03.340	RPM:1958.48

11:10:03.385	RPM:1958.99

11:10:03.411	RPM:1959.50

11:10:03.435	RPM:1960.02

11:10:03.475	RPM:1960.27

11:10:03.500	RPM:1960.78

11:10:03.525	RPM:1961.55

11:10:03.566	RPM:1962.07

11:10:03.591	RPM:1962.32

11:10:03.617	RPM:1963.09
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

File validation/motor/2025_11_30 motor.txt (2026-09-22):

11:21:45.958	RPM Sensor Ready (Adaptive Mode)...
RPM:0

11:21:47.922	RPM:30.36

11:21:48.160	RPM:248.43

11:21:48.342	RPM:334.42

11:21:48.506	RPM:395.64

11:21:48.641	RPM:444.31

11:21:48.760	RPM:484.98

11:21:48.881	RPM:520.04

11:21:48.985	RPM:551.05

11:21:49.091	RPM:578.75

11:21:49.181	RPM:603.72

11:21:49.285	RPM:626.41

11:21:49.376	RPM:647.25

11:21:49.466	RPM:666.58

11:21:49.557	RPM:684.43

11:21:49.631	RPM:701.16

11:21:49.720	RPM:716.71

11:21:49.811	RPM:731.31

11:21:49.886	RPM:745.01

11:21:49.960	RPM:758.00

11:21:50.051	RPM:770.14

11:21:50.111	RPM:781.70

11:21:50.201	RPM:792.69

11:21:50.276	RPM:803.21

11:21:50.335	RPM:813.32

11:21:50.411	RPM:822.68

11:21:50.486	RPM:831.72

11:21:50.560	RPM:840.34

11:21:50.635	RPM:848.75

11:21:50.696	RPM:856.80

11:21:50.770	RPM:864.45

11:21:50.831	RPM:871.79

11:21:50.906	RPM:878.99

11:21:50.965	RPM:885.69

11:21:51.040	RPM:892.22

11:21:51.101	RPM:898.42

11:21:51.176	RPM:904.43

11:21:51.235	RPM:910.19

11:21:51.311	RPM:915.75

11:21:51.370	RPM:920.81

11:21:51.431	RPM:925.58

11:21:51.506	RPM:930.12

11:21:51.566	RPM:934.46

11:21:51.625	RPM:938.67

11:21:51.701	RPM:942.63

11:21:51.760	RPM:946.37

11:21:51.821	RPM:949.79

11:21:51.881	RPM:952.93

11:21:51.941	RPM:955.90

11:21:52.001	RPM:958.71

11:21:52.076	RPM:961.35

11:21:52.135	RPM:963.82

11:21:52.195	RPM:966.12

11:21:52.256	RPM:968.30

11:21:52.316	RPM:970.25

11:21:52.375	RPM:972.07

11:21:52.435	RPM:973.58

11:21:52.496	RPM:975.23

11:21:52.556	RPM:976.69

11:21:52.629	RPM:978.03

11:21:52.690	RPM:979.37

11:21:52.751	RPM:980.71

11:21:52.811	RPM:981.80

11:21:52.870	RPM:982.90

11:21:52.931	RPM:983.86

11:21:52.991	RPM:984.83

11:21:53.049	RPM:985.61

11:21:53.110	RPM:986.45

11:21:53.170	RPM:987.23

11:21:53.231	RPM:988.01

11:21:53.290	RPM:988.66

11:21:53.351	RPM:989.18

11:21:53.410	RPM:989.64

11:21:53.470	RPM:990.16

11:21:53.531	RPM:990.56

11:21:53.591	RPM:990.95

11:21:53.666	RPM:991.41

11:21:53.726	RPM:991.80

11:21:53.786	RPM:992.26

11:21:53.846	RPM:992.52

11:21:53.906	RPM:992.92

11:21:53.965	RPM:993.31

11:21:54.024	RPM:993.51

11:21:54.085	RPM:993.84

11:21:54.146	RPM:994.30

11:21:54.205	RPM:994.50

11:21:54.266	RPM:994.69

11:21:54.326	RPM:994.83

11:21:54.385	RPM:994.89

11:21:54.446	RPM:995.09

11:21:54.505	RPM:995.29

11:21:54.565	RPM:995.62

11:21:54.626	RPM:995.69

11:21:54.685	RPM:996.02

11:21:54.746	RPM:996.15

11:21:54.805	RPM:996.28

11:21:54.866	RPM:996.41

11:21:54.926	RPM:996.68

11:21:54.985	RPM:996.88

11:21:55.046	RPM:996.88

11:21:55.106	RPM:997.14

11:21:55.165	RPM:997.27

11:21:55.225	RPM:997.41

11:21:55.286	RPM:997.61

11:21:55.346	RPM:997.74

11:21:55.405	RPM:997.80

11:21:55.466	RPM:997.87

11:21:55.526	RPM:997.94

11:21:55.586	RPM:998.00

11:21:55.646	RPM:998.20

11:21:55.706	RPM:998.27

11:21:55.766	RPM:998.27

11:21:55.826	RPM:998.40

11:21:55.886	RPM:998.47

11:21:55.946	RPM:998.47

11:21:56.005	RPM:998.67

11:21:56.066	RPM:998.80

11:21:56.126	RPM:998.93

11:21:56.186	RPM:998.87

11:21:56.246	RPM:998.80

11:21:56.306	RPM:998.87

11:21:56.366	RPM:999.00

11:21:56.426	RPM:999.00

11:21:56.486	RPM:999.00

11:21:56.546	RPM:999.13

11:21:56.605	RPM:999.20

11:21:56.666	RPM:999.20

11:21:56.726	RPM:999.27

11:21:56.786	RPM:999.27

11:21:56.846	RPM:999.33

11:21:56.906	RPM:999.40

11:21:56.966	RPM:999.40

11:21:57.026	RPM:999.47

11:21:57.086	RPM:999.53

11:21:57.146	RPM:999.47

11:21:57.205	RPM:999.53

11:21:57.265	RPM:999.53

11:21:57.326	RPM:999.47

11:21:57.386	RPM:999.47

11:21:57.446	RPM:999.53

11:21:57.506	RPM:999.60

11:21:57.566	RPM:999.67

11:21:57.624	RPM:999.67

11:21:57.686	RPM:999.67

11:21:57.746	RPM:999.60

11:21:57.805	RPM:999.67

11:21:57.866	RPM:999.67

11:21:57.926	RPM:999.67

11:21:57.986	RPM:999.73

11:21:58.046	RPM:999.73

11:21:58.106	RPM:999.80

11:21:58.166	RPM:999.80

11:21:58.225	RPM:999.80

11:21:58.286	RPM:999.73

11:21:58.346	RPM:999.80

11:21:58.405	RPM:999.87

11:21:58.466	RPM:999.93

11:21:58.526	RPM:999.93

11:21:58.586	RPM:999.93

11:21:58.645	RPM:999.87

11:21:58.706	RPM:999.87

11:21:58.765	RPM:999.87

11:21:58.826	RPM:999.87

11:21:58.886	RPM:999.87

11:21:58.946	RPM:1000.00

11:21:59.005	RPM:999.93

11:21:59.066	RPM:999.93

11:21:59.126	RPM:999.93

11:21:59.186	RPM:999.93

11:21:59.246	RPM:999.87

11:21:59.306	RPM:1000.00

11:21:59.366	RPM:1000.07

11:21:59.426	RPM:1000.00

11:21:59.486	RPM:999.93

11:21:59.546	RPM:999.87

11:21:59.605	RPM:999.80

11:21:59.665	RPM:999.93

11:21:59.726	RPM:999.93

11:21:59.786	RPM:1000.07

11:21:59.846	RPM:1000.07

11:21:59.906	RPM:1000.07

11:21:59.966	RPM:1000.07

11:22:00.024	RPM:1000.07

11:22:00.086	RPM:999.93

11:22:00.145	RPM:999.93

11:22:00.205	RPM:999.93

11:22:00.266	RPM:1000.07

11:22:00.326	RPM:1000.07

11:22:00.386	RPM:1000.00

11:22:00.446	RPM:1000.00

11:22:00.506	RPM:999.93

11:22:00.566	RPM:1000.00

11:22:00.626	RPM:1000.00

11:22:00.685	RPM:1000.00

11:22:00.745	RPM:999.93

11:22:00.805	RPM:999.87

11:22:00.865	RPM:999.87

11:22:00.925	RPM:999.73

11:22:00.986	RPM:999.73

11:22:01.045	RPM:999.73

11:22:01.106	RPM:999.67

11:22:01.165	RPM:999.73

11:22:01.225	RPM:999.73

11:22:01.286	RPM:999.80

11:22:01.346	RPM:999.67

11:22:01.405	RPM:999.73

11:22:01.466	RPM:999.67

11:22:01.526	RPM:999.67

11:22:01.586	RPM:999.67

11:22:01.646	RPM:999.60

11:22:01.706	RPM:999.60

11:22:01.766	RPM:999.73

11:22:01.826	RPM:999.60

11:22:01.886	RPM:999.67

11:22:01.946	RPM:999.80

11:22:02.005	RPM:999.87

11:22:02.066	RPM:999.80

11:22:02.125	RPM:999.73

11:22:02.186	RPM:999.80

11:22:02.246	RPM:999.80

11:22:02.306	RPM:999.80

11:22:02.365	RPM:999.73

11:22:02.426	RPM:999.80

11:22:02.486	RPM:1002.20

11:22:02.546	RPM:1008.34

11:22:02.605	RPM:1015.85

11:22:02.665	RPM:1024.80

11:22:02.724	RPM:1034.55

11:22:02.786	RPM:1045.15

11:22:02.846	RPM:1056.26

11:22:02.891	RPM:1067.84

11:22:02.951	RPM:1079.60

11:22:03.011	RPM:1091.39

11:22:03.056	RPM:1103.18

11:22:03.116	RPM:1114.74

11:22:03.160	RPM:1126.21

11:22:03.220	RPM:1137.31

11:22:03.266	RPM:1148.19

11:22:03.324	RPM:1158.75

11:22:03.370	RPM:1168.86

11:22:03.430	RPM:1178.78

11:22:03.475	RPM:1188.31

11:22:03.520	RPM:1197.60

11:22:03.580	RPM:1206.27

11:22:03.625	RPM:1214.87

11:22:03.669	RPM:1222.79

11:22:03.730	RPM:1231.02

11:22:03.776	RPM:1238.65

11:22:03.821	RPM:1245.85

11:22:03.866	RPM:1253.03

11:22:03.910	RPM:1259.76

11:22:03.970	RPM:1266.25

11:22:04.016	RPM:1272.48

11:22:04.060	RPM:1278.66

11:22:04.106	RPM:1284.47

11:22:04.151	RPM:1289.99

11:22:04.195	RPM:1295.34

11:22:04.240	RPM:1300.62

11:22:04.286	RPM:1305.82

11:22:04.330	RPM:1310.73

11:22:04.375	RPM:1315.44

11:22:04.420	RPM:1319.84

11:22:04.466	RPM:1324.27

11:22:04.525	RPM:1328.37

11:22:04.570	RPM:1332.50

11:22:04.615	RPM:1336.42

11:22:04.660	RPM:1340.36

11:22:04.705	RPM:1344.21

11:22:04.733	RPM:1347.83

11:22:04.781	RPM:1351.59

11:22:04.825	RPM:1355.14

11:22:04.870	RPM:1358.20

11:22:04.915	RPM:1361.53

11:22:04.960	RPM:1364.75

11:22:05.005	RPM:1367.74

11:22:05.050	RPM:1370.61

11:22:05.096	RPM:1373.75

11:22:05.140	RPM:1376.78

11:22:05.186	RPM:1379.44

11:22:05.230	RPM:1381.98

11:22:05.259	RPM:1384.27

11:22:05.305	RPM:1386.83

11:22:05.349	RPM:1389.53

11:22:05.395	RPM:1392.24

11:22:05.440	RPM:1394.44

11:22:05.486	RPM:1396.26

11:22:05.530	RPM:1398.21

11:22:05.558	RPM:1400.69

11:22:05.605	RPM:1402.79

11:22:05.650	RPM:1404.89

11:22:05.696	RPM:1406.73

11:22:05.740	RPM:1408.98

11:22:05.785	RPM:1411.10

11:22:05.830	RPM:1412.70

11:22:05.858	RPM:1414.56

11:22:05.905	RPM:1416.30

11:22:05.950	RPM:1417.77

11:22:05.995	RPM:1419.11

11:22:06.040	RPM:1420.59

11:22:06.086	RPM:1422.21

11:22:06.113	RPM:1423.56

11:22:06.160	RPM:1425.31

11:22:06.205	RPM:1427.08

11:22:06.250	RPM:1428.71

11:22:06.280	RPM:1429.80

11:22:06.325	RPM:1431.30

11:22:06.370	RPM:1433.08

11:22:06.415	RPM:1434.31

11:22:06.460	RPM:1435.96

11:22:06.489	RPM:1437.61

11:22:06.535	RPM:1438.71

11:22:06.581	RPM:1439.95

11:22:06.625	RPM:1440.92

11:22:06.670	RPM:1442.31

11:22:06.698	RPM:1443.28

11:22:06.745	RPM:1444.67

11:22:06.791	RPM:1445.92

11:22:06.835	RPM:1446.90

11:22:06.881	RPM:1448.16

11:22:06.909	RPM:1448.58

11:22:06.955	RPM:1449.56

11:22:06.999	RPM:1450.54

11:22:07.039	RPM:1451.52

11:22:07.102	RPM:1452.50
RPM:1452.93

11:22:07.165	RPM:1454.05

11:22:07.193	RPM:1455.18

11:22:07.240	RPM:1456.45

11:22:07.286	RPM:1457.16

11:22:07.330	RPM:1458.01

11:22:07.358	RPM:1458.86

11:22:07.405	RPM:1460.00

11:22:07.449	RPM:1460.28

11:22:07.495	RPM:1460.71

11:22:07.525	RPM:1461.42

11:22:07.570	RPM:1462.42

11:22:07.615	RPM:1463.27

11:22:07.660	RPM:1463.70

11:22:07.690	RPM:1464.13

11:22:07.735	RPM:1464.70

11:22:07.781	RPM:1465.56

11:22:07.825	RPM:1465.99

11:22:07.855	RPM:1466.85

11:22:07.900	RPM:1467.42

11:22:07.945	RPM:1468.14

11:22:07.991	RPM:1468.86

11:22:08.018	RPM:1469.44

11:22:08.065	RPM:1470.44

11:22:08.094	RPM:1471.02

11:22:08.140	RPM:1471.89

11:22:08.186	RPM:1472.18

11:22:08.230	RPM:1472.61

11:22:08.259	RPM:1472.90

11:22:08.305	RPM:1473.91

11:22:08.350	RPM:1474.35

11:22:08.394	RPM:1475.07

11:22:08.425	RPM:1475.65

11:22:08.470	RPM:1476.09

11:22:08.515	RPM:1476.38

11:22:08.560	RPM:1476.38

11:22:08.587	RPM:1476.52

11:22:08.635	RPM:1477.25

11:22:08.681	RPM:1477.25

11:22:08.707	RPM:1477.10

11:22:08.755	RPM:1477.54

11:22:08.800	RPM:1478.27

11:22:08.830	RPM:1478.71

11:22:08.875	RPM:1479.14

11:22:08.920	RPM:1479.58

11:22:08.965	RPM:1480.17

11:22:08.992	RPM:1480.90

11:22:09.040	RPM:1481.19

11:22:09.086	RPM:1481.04

11:22:09.113	RPM:1481.19

11:22:09.160	RPM:1481.77

11:22:09.205	RPM:1482.21

11:22:09.234	RPM:1482.65

11:22:09.280	RPM:1482.95

11:22:09.325	RPM:1483.09

11:22:09.370	RPM:1483.39

11:22:09.397	RPM:1483.39

11:22:09.445	RPM:1483.39

11:22:09.474	RPM:1483.68

11:22:09.520	RPM:1484.27

11:22:09.565	RPM:1484.27

11:22:09.610	RPM:1484.71

11:22:09.640	RPM:1484.85

11:22:09.685	RPM:1485.15

11:22:09.730	RPM:1485.59

11:22:09.756	RPM:1486.03

11:22:09.805	RPM:1485.88

11:22:09.850	RPM:1486.62

11:22:09.895	RPM:1486.77

11:22:09.922	RPM:1486.62

11:22:09.970	RPM:1486.77

11:22:10.015	RPM:1486.92

11:22:10.043	RPM:1487.51

11:22:10.090	RPM:1487.36

11:22:10.135	RPM:1487.36

11:22:10.162	RPM:1487.65

11:22:10.210	RPM:1488.54

11:22:10.255	RPM:1488.83

11:22:10.282	RPM:1489.43

11:22:10.330	RPM:1489.87

11:22:10.375	RPM:1489.87

11:22:10.405	RPM:1489.72

11:22:10.450	RPM:1489.57

11:22:10.495	RPM:1489.72

11:22:10.525	RPM:1489.87

11:22:10.570	RPM:1489.72

11:22:10.615	RPM:1489.87

11:22:10.660	RPM:1489.87

11:22:10.687	RPM:1490.16

11:22:10.735	RPM:1490.46

11:22:10.765	RPM:1490.46

11:22:10.810	RPM:1490.76

11:22:10.855	RPM:1491.05

11:22:10.900	RPM:1491.35

11:22:10.930	RPM:1491.94

11:22:10.975	RPM:1492.54

11:22:11.020	RPM:1492.69

11:22:11.048	RPM:1492.83

11:22:11.095	RPM:1492.83

11:22:11.140	RPM:1492.83

11:22:11.185	RPM:1492.69

11:22:11.213	RPM:1492.83

11:22:11.260	RPM:1492.98

11:22:11.290	RPM:1493.43

11:22:11.335	RPM:1493.43

11:22:11.380	RPM:1493.73

11:22:11.410	RPM:1493.58

11:22:11.455	RPM:1493.58

11:22:11.500	RPM:1493.73

11:22:11.545	RPM:1493.73

11:22:11.573	RPM:1493.43

11:22:11.620	RPM:1493.43

11:22:11.650	RPM:1493.43

11:22:11.695	RPM:1493.28

11:22:11.740	RPM:1493.73

11:22:11.785	RPM:1494.02

11:22:11.813	RPM:1494.32

11:22:11.860	RPM:1494.47

11:22:11.905	RPM:1494.77

11:22:11.932	RPM:1494.92

11:22:11.980	RPM:1494.62

11:22:12.025	RPM:1495.07

11:22:12.051	RPM:1495.22

11:22:12.100	RPM:1495.96

11:22:12.145	RPM:1495.66

11:22:12.174	RPM:1495.51

11:22:12.220	RPM:1495.96

11:22:12.265	RPM:1495.66

11:22:12.294	RPM:1495.66

11:22:12.340	RPM:1495.96

11:22:12.385	RPM:1495.66

11:22:12.413	RPM:1495.66

11:22:12.460	RPM:1495.96

11:22:12.505	RPM:1496.11

11:22:12.535	RPM:1495.81

11:22:12.580	RPM:1496.11

11:22:12.625	RPM:1496.86

11:22:12.655	RPM:1496.26

11:22:12.700	RPM:1495.96

11:22:12.745	RPM:1496.26

11:22:12.790	RPM:1496.56

11:22:12.817	RPM:1496.56

11:22:12.865	RPM:1496.71

11:22:12.894	RPM:1496.56

11:22:12.940	RPM:1497.01

11:22:12.985	RPM:1497.16

11:22:13.014	RPM:1496.86

11:22:13.060	RPM:1496.56

11:22:13.105	RPM:1497.01

11:22:13.150	RPM:1496.56

11:22:13.177	RPM:1496.86

11:22:13.225	RPM:1497.01

11:22:13.255	RPM:1497.01

11:22:13.300	RPM:1497.16

11:22:13.344	RPM:1497.01

11:22:13.375	RPM:1496.56

11:22:13.420	RPM:1496.86

11:22:13.465	RPM:1496.56

11:22:13.510	RPM:1496.56

11:22:13.538	RPM:1496.41

11:22:13.585	RPM:1496.86

11:22:13.630	RPM:1497.45

11:22:13.656	RPM:1497.30

11:22:13.705	RPM:1497.30

11:22:13.735	RPM:1497.01

11:22:13.780	RPM:1496.86

11:22:13.825	RPM:1497.16

11:22:13.869	RPM:1497.16

11:22:13.900	RPM:1497.01

11:22:13.945	RPM:1497.60

11:22:13.990	RPM:1497.60

11:22:14.017	RPM:1498.05

11:22:14.064	RPM:1498.20

11:22:14.110	RPM:1498.20

11:22:14.137	RPM:1498.20

11:22:14.185	RPM:1498.50

11:22:14.230	RPM:1498.35

11:22:14.259	RPM:1498.50

11:22:14.305	RPM:1498.65

11:22:14.350	RPM:1498.80

11:22:14.377	RPM:1499.40

11:22:14.425	RPM:1499.85

11:22:14.470	RPM:1499.55

11:22:14.497	RPM:1499.25

11:22:14.545	RPM:1499.25

11:22:14.590	RPM:1499.40

11:22:14.619	RPM:1499.40

11:22:14.665	RPM:1499.55

11:22:14.710	RPM:1499.25

11:22:14.738	RPM:1499.25

11:22:14.785	RPM:1499.85

11:22:14.830	RPM:1499.70

11:22:14.856	RPM:1499.55

11:22:14.905	RPM:1499.40

11:22:14.950	RPM:1499.40

11:22:14.977	RPM:1499.25

11:22:15.025	RPM:1499.40

11:22:15.070	RPM:1500.00

11:22:15.100	RPM:1499.55

11:22:15.145	RPM:1499.40

11:22:15.190	RPM:1499.55

11:22:15.217	RPM:1500.00

11:22:15.265	RPM:1499.70

11:22:15.310	RPM:1499.55

11:22:15.338	RPM:1499.55

11:22:15.385	RPM:1499.25

11:22:15.430	RPM:1498.95

11:22:15.459	RPM:1498.80

11:22:15.505	RPM:1498.95

11:22:15.550	RPM:1498.65

11:22:15.579	RPM:1497.90

11:22:15.625	RPM:1498.05

11:22:15.670	RPM:1498.50

11:22:15.697	RPM:1498.80

11:22:15.745	RPM:1498.80

11:22:15.790	RPM:1498.95

11:22:15.819	RPM:1498.80

11:22:15.864	RPM:1499.25

11:22:15.910	RPM:1499.70

11:22:15.938	RPM:1499.25

11:22:15.985	RPM:1498.95

11:22:16.030	RPM:1498.95

11:22:16.057	RPM:1498.95

11:22:16.104	RPM:1498.80

11:22:16.150	RPM:1498.95

11:22:16.179	RPM:1498.95

11:22:16.224	RPM:1499.10

11:22:16.269	RPM:1499.10

11:22:16.300	RPM:1498.80

11:22:16.345	RPM:1498.95

11:22:16.390	RPM:1498.65

11:22:16.417	RPM:1498.80

11:22:16.465	RPM:1498.50

11:22:16.509	RPM:1498.35

11:22:16.540	RPM:1498.80

11:22:16.585	RPM:1498.65

11:22:16.630	RPM:1498.95

11:22:16.659	RPM:1498.80

11:22:16.705	RPM:1498.80

11:22:16.750	RPM:1498.65

11:22:16.779	RPM:1498.50

11:22:16.825	RPM:1498.95

11:22:16.870	RPM:1498.80

11:22:16.915	RPM:1498.35

11:22:16.943	RPM:1498.65

11:22:16.990	RPM:1499.10

11:22:17.019	RPM:1499.25

11:22:17.065	RPM:1499.55

11:22:17.110	RPM:1499.55

11:22:17.139	RPM:1499.10

11:22:17.185	RPM:1499.10

11:22:17.230	RPM:1499.25

11:22:17.275	RPM:1499.25

11:22:17.302	RPM:1499.10

11:22:17.350	RPM:1499.25

11:22:17.379	RPM:1499.25

11:22:17.425	RPM:1499.25

11:22:17.470	RPM:1499.40

11:22:17.500	RPM:1498.95

11:22:17.545	RPM:1498.65

11:22:17.590	RPM:1498.95

11:22:17.616	RPM:1499.25

11:22:17.665	RPM:1499.10

11:22:17.710	RPM:1498.50

11:22:17.755	RPM:1498.20

11:22:17.782	RPM:1498.35

11:22:17.830	RPM:1498.50

11:22:17.859	RPM:1498.65

11:22:17.905	RPM:1498.95

11:22:17.950	RPM:1499.25

11:22:17.979	RPM:1499.10

11:22:18.025	RPM:1499.10

11:22:18.069	RPM:1499.10

11:22:18.115	RPM:1498.95

11:22:18.143	RPM:1498.65

11:22:18.190	RPM:1498.80

11:22:18.219	RPM:1499.40

11:22:18.265	RPM:1499.55

11:22:18.309	RPM:1499.40

11:22:18.339	RPM:1499.70

11:22:18.385	RPM:1499.25

11:22:18.430	RPM:1499.70

11:22:18.475	RPM:1499.25

11:22:18.501	RPM:1499.25

11:22:18.550	RPM:1499.25

11:22:18.579	RPM:1499.85

11:22:18.625	RPM:1500.15

11:22:18.670	RPM:1499.85

11:22:18.699	RPM:1499.70

11:22:18.745	RPM:1499.55

11:22:18.790	RPM:1499.10

11:22:18.835	RPM:1499.55

11:22:18.862	RPM:1499.25

11:22:18.910	RPM:1499.40

11:22:18.955	RPM:1499.25

11:22:18.982	RPM:1499.25

11:22:19.030	RPM:1499.25

11:22:19.059	RPM:1499.55

11:22:19.105	RPM:1499.70
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

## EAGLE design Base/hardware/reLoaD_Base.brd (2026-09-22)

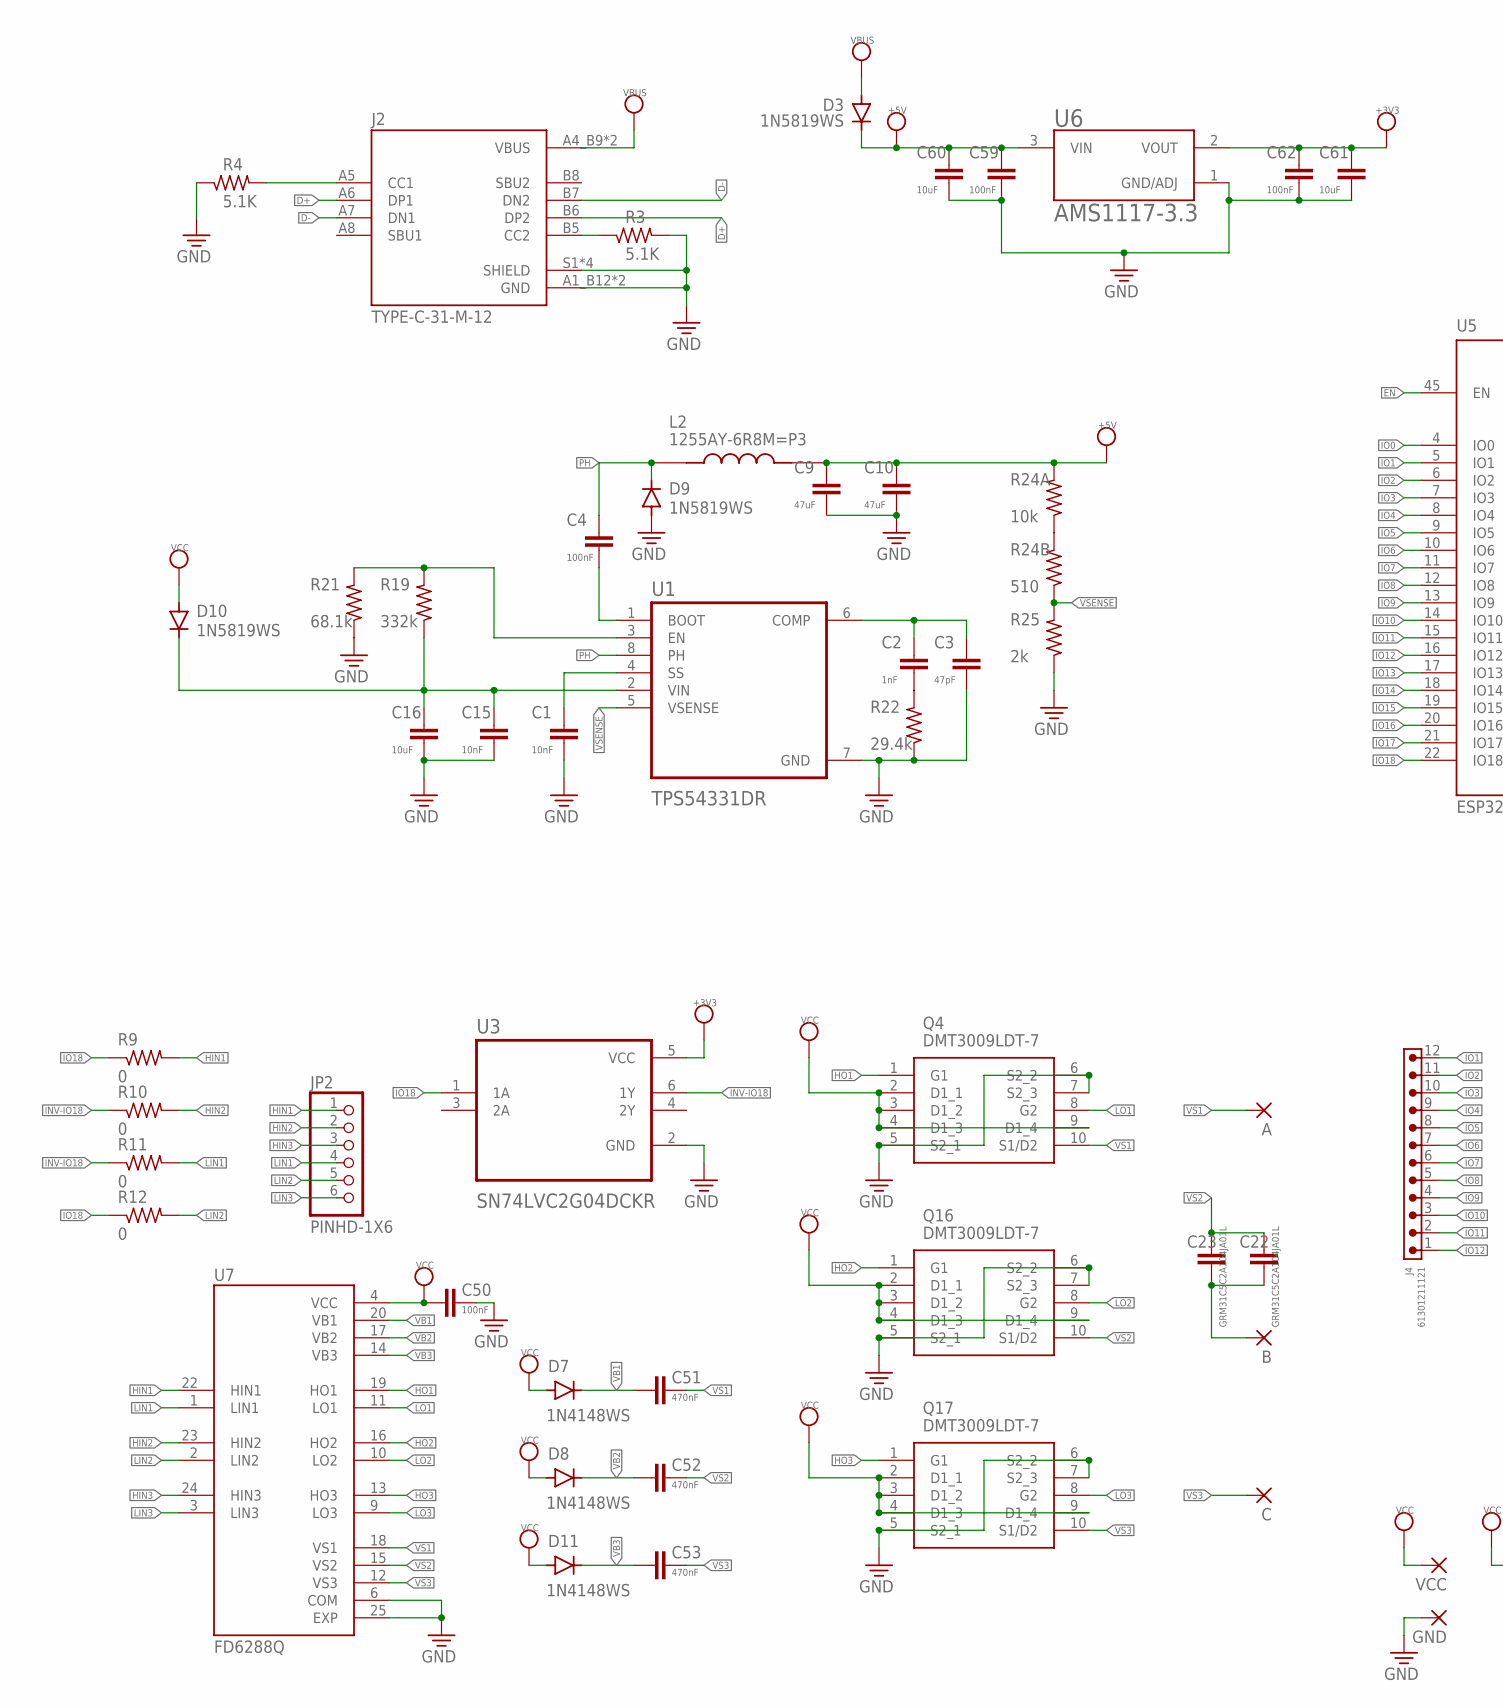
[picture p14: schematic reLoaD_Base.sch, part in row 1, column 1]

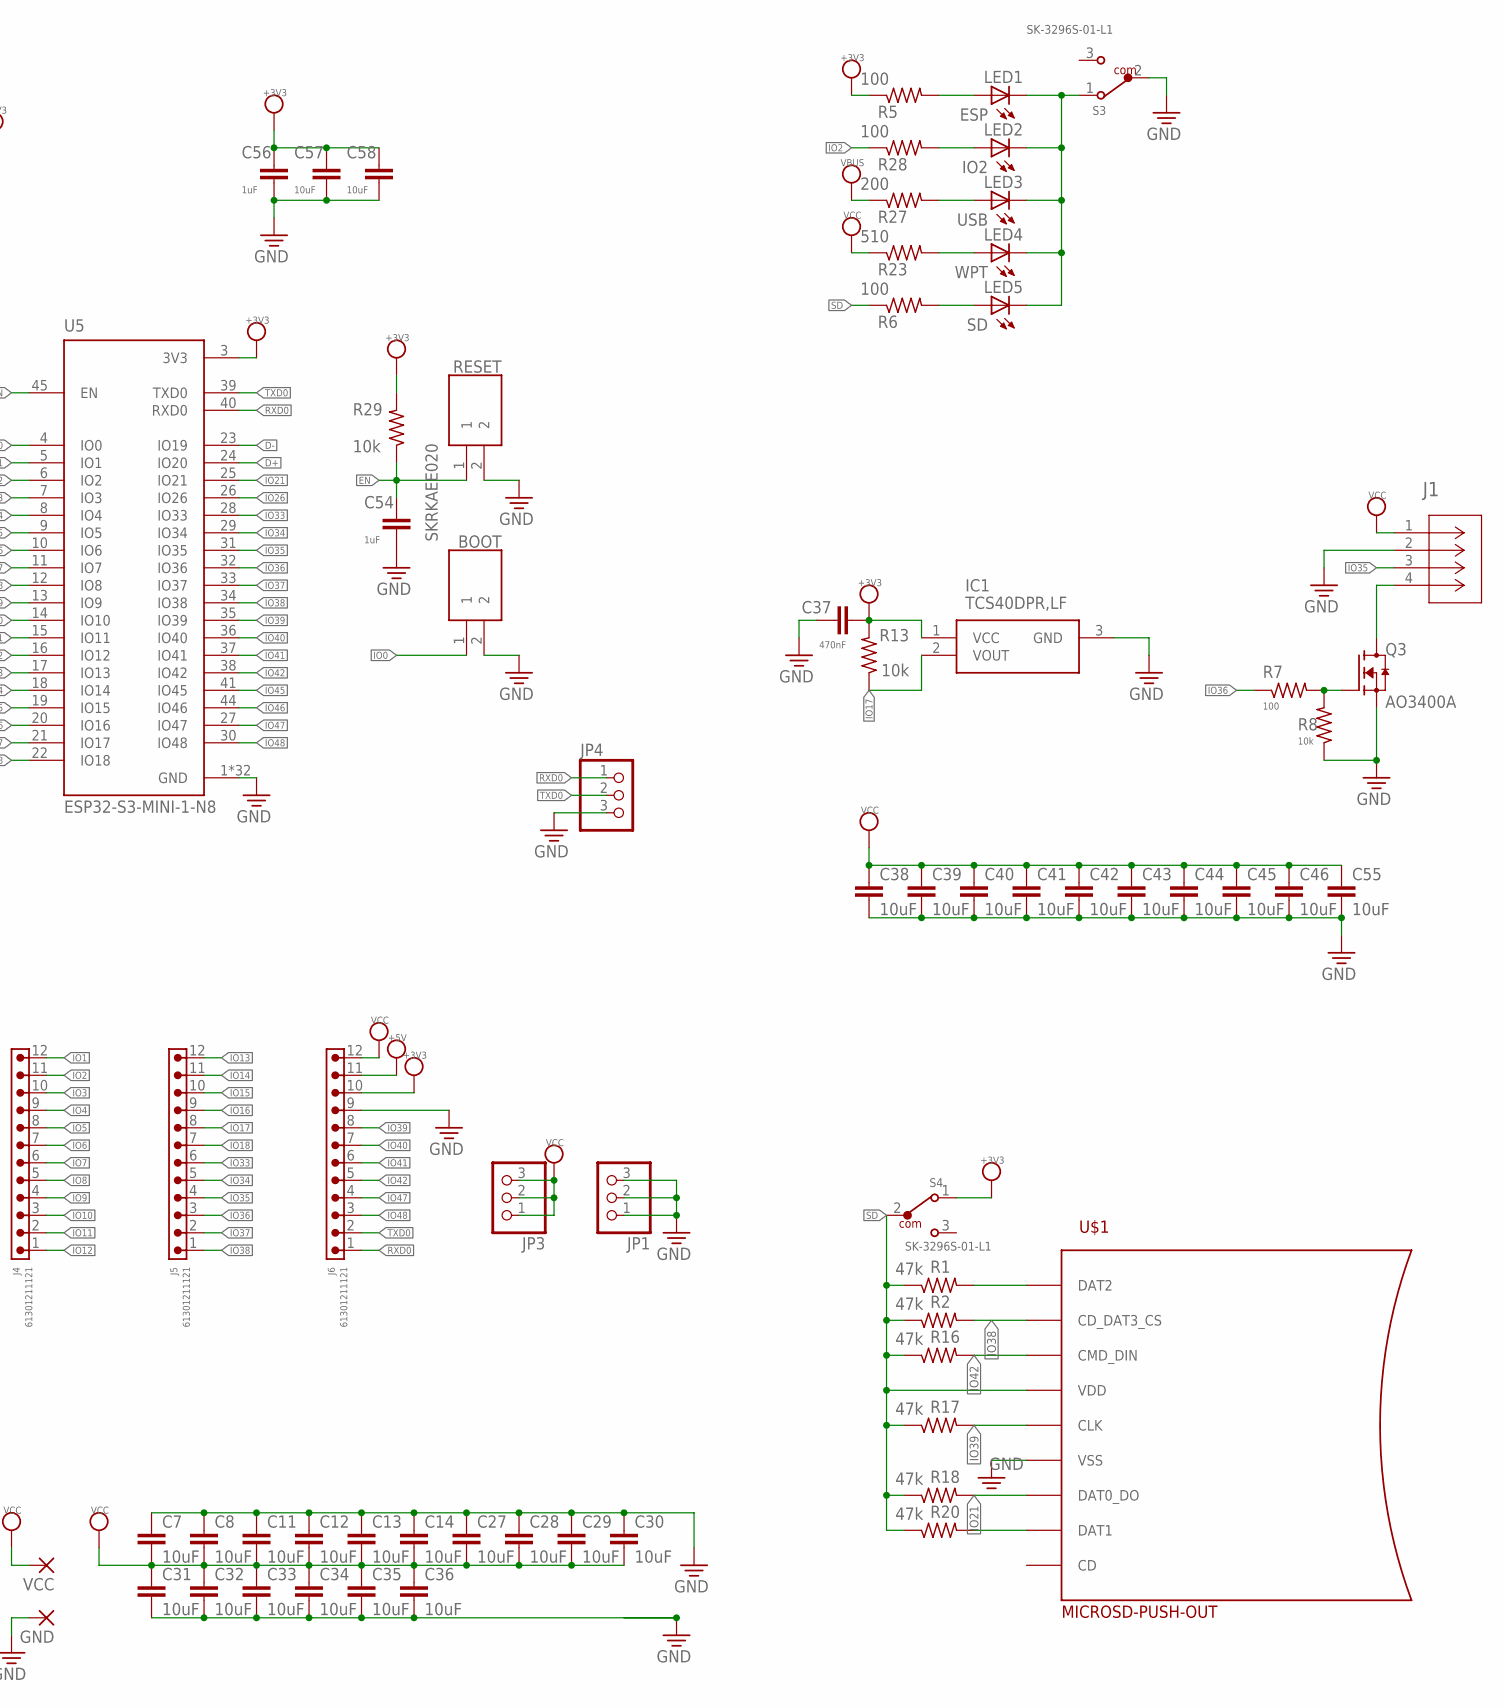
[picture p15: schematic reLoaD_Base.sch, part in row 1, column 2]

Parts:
A: 3,81/1,4
B: 3,81/1,4
BOOT: SKRKAEE020
C: 3,81/1,4
C1, C15: 10nF; C0603K
C2: 1nF; C0603K
C3: 47pF; C0603K
C4, C50, C59, C62: 100nF; C0603K
C7, C8, C11, C12, C13, C14, C27, C28, C29, C30, C31, C32, C33, C34, C35, C36, C38, C39, C40, C41, C42, C43, C44, C45, C46, C55: 10uF; C0805K
C9, C10: 47uF; C0603K
C16, C57, C58, C60, C61: 10uF; C0603K
C22, C23: GRM31C5C2A104JA01L; C1206K
C37, C51, C52, C53: 470nF; C0603K
C54, C56: 1uF; C0603K
D3, D9, D10: 1N5819WS; SOD323-W
D7, D8, D11: 1N4148WS; SOD-323
GND: 3,81/1,4
IC1: TCS40DPR,LF; SOTFL95P240X88-3N
J1: S4B-XH-SM4-TBCONN4_S4B-XH_JST; CONN4_S4B-XH_JST
J2: TYPE-C-31-M-12; HRO_TYPE-C-31-M-12
J4, J5, J6: 61301211121
JP1, JP3, JP4: PINHD-1X3; 1X03
JP2: PINHD-1X6; 1X06
L2: 1255AY-6R8M=P3; IND_1255AY-6R8M=P3
LED1: ESP; CHIPLED_0805
LED2: IO2; CHIPLED_0805
LED3: USB; CHIPLED_0805
LED4: WPT; CHIPLED_0805
LED5: SD; CHIPLED_0805
Q3: AO3400A; SOT95P280X125-3N
Q4, Q16, Q17: DMT3009LDT-7; DMT3009LDT7
R1, R2, R16, R17, R18, R20: 47k; R0603
R3, R4: 5.1K; R0603
R5, R6, R7, R28: 100; R0603
R8, R13, R24A, R29: 10k; R0603
R9, R10, R11, R12: 0; R0603
R19: 332k; R0603
R21: 68.1k; R0603
R22: 29.4k; R0603
R23, R24B: 510; R0603
R25: 2k; R0603
R27: 200; R0603
RESET: SKRKAEE020
S3, S4: SK-3296S-01-L1; 450404015514
U1: TPS54331DR; SOIC127P599X175-8N
U3: SN74LVC2G04DCKR; SOT65P210X110-6N
U5: ESP32-S3-MINI-1-N8; XCVR_ESP32-S3-MINI-1-N8
U6: AMS1117-3.3; SOT229P700X180-4N
U7: FD6288Q; QFN50P400X400X90-25N
U$1: MICROSD-PUSH-OUT
VCC: 3,81/1,4

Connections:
+3V3: C37.2, C56.1, C57.1, C58.1, C61.1, C62.1, IC1.1 (VCC), J6.10, R5.1, R13.2, R29.2, S4.1, U3.5 (VCC), U5.3 (3V3), U6.2 (VOUT)
+5V: C9.1, C10.1, C59.1, C60.1, D3.C, J6.11, L2.2, R24A.2, U6.3 (VIN)
COIL2R1: B.1, C22.1, C23.1
D+: J2.A6 (DP1), J2.B6 (DP2), U5.24 (IO20)
D-: J2.A7 (DN1), J2.B7 (DN2), U5.23 (IO19)
DAT2: R1.2, U$1.1 (DAT2)
EN: C54.1, R29.1, RESET.1, U5.45 (EN)
GND: BOOT.2, C1.2, C3.2, C7.1, C8.1, C9.2, C10.2, C11.1, C12.1, C13.1, C14.1, C15.2, C16.2, C27.1, C28.1, C29.1, C30.1, C31.2, C32.2, C33.2, C34.2, C35.2, C36.2, C37.1, C38.2, C39.2, C40.2, C41.2, C42.2, C43.2, C44.2, C45.2, C46.2, C50.1, C54.2, C55.2, C56.2, C57.2, C58.2, C59.2, C60.2, C61.2, C62.2, D9.A, GND.1, IC1.3 (GND), J1.2, J2.A1_B12 (GND), J2.B1_A12 (GND), J2.S1 (SHIELD), J2.S2 (SHIELD), J2.S3 (SHIELD), J2.S4 (SHIELD), J6.9, JP1.1, JP1.2, JP1.3, JP4.3, Q3.2 (S), Q4.5 (S2_1), Q4.6 (S2_2), Q4.7 (S2_3), Q16.5 (S2_1), Q16.6 (S2_2), Q16.7 (S2_3), Q17.5 (S2_1), Q17.6 (S2_2), Q17.7 (S2_3), R3.2, R4.1, R8.1, R21.1, R22.1, R25.1, RESET.2, S3.2, U1.7 (GND), U3.2 (GND), U5.1 (GND), U5.2 (GND), U5.42 (GND), U5.43 (GND), U5.46 (GND), U5.47 (GND), U5.48 (GND), U5.49 (GND), U5.50 (GND), U5.51 (GND), U5.52 (GND), U5.53 (GND), U5.54 (GND), U5.55 (GND), U5.56 (GND), U5.57 (GND), U5.58 (GND), U5.59 (GND), U5.60 (GND), U5.61 (GND), U5.61_1 (GND), U5.61_2 (GND), U5.61_3 (GND), U5.61_4 (GND), U5.61_5 (GND), U5.61_6 (GND), U5.61_7 (GND), U5.61_8 (GND), U5.62 (GND), U5.63 (GND), U5.64 (GND), U5.65 (GND), U6.1 (GND/ADJ), U7.6 (COM), U7.25 (EXP), U$1.6 (VSS), U$1.G1 (VSS), U$1.G2 (VSS), U$1.G3 (VSS), U$1.G4 (VSS)
HIN1: JP2.1, R9.2, U7.22 (HIN1)
HIN2: JP2.2, R10.2, U7.23 (HIN2)
HIN3: JP2.3, U7.24 (HIN3)
HO1: Q4.1 (G1), U7.19 (HO1)
HO2: Q16.1 (G1), U7.16 (HO2)
HO3: Q17.1 (G1), U7.13 (HO3)
INV-IO18: R10.1, R11.1, U3.6 (1Y)
IO0: BOOT.1, U5.4 (IO0)
IO1: J4.12, U5.5 (IO1)
IO2: J4.11, R28.1, U5.6 (IO2)
IO3: J4.10, U5.7 (IO3)
IO4: J4.9, U5.8 (IO4)
IO5: J4.8, U5.9 (IO5)
IO6: J4.7, U5.10 (IO6)
IO7: J4.6, U5.11 (IO7)
IO8: J4.5, U5.12 (IO8)
IO9: J4.4, U5.13 (IO9)
IO10: J4.3, U5.14 (IO10)
IO11: J4.2, U5.15 (IO11)
IO12: J4.1, U5.16 (IO12)
IO13: J5.12, U5.17 (IO13)
IO14: J5.11, U5.18 (IO14)
IO15: J5.10, U5.19 (IO15)
IO16: J5.9, U5.20 (IO16)
IO17: IC1.2 (VOUT), J5.8, R13.1, U5.21 (IO17)
IO18: J5.7, R9.1, R12.1, U3.1 (1A), U5.22 (IO18)
IO21: R18.2, U5.25 (IO21), U$1.7 (DAT0_DO)
IO26: U5.26 (IO26)
IO33: J5.6, U5.28 (IO33)
IO34: J5.5, U5.29 (IO34)
IO35: J1.3, J5.4, U5.31 (IO35)
IO36: J5.3, R7.1, U5.32 (IO36)
IO37: J5.2, U5.33 (IO37)
IO38: J5.1, R2.2, U5.34 (IO38), U$1.2 (CD_DAT3_CS)
IO39: J6.8, R17.2, U5.35 (IO39), U$1.5 (CLK)
IO40: J6.7, U5.36 (IO40)
IO41: J6.6, U5.37 (IO41)
IO42: J6.5, R16.2, U5.38 (IO42), U$1.3 (CMD_DIN)
IO45: U5.41 (IO45)
IO46: U5.44 (IO46)
IO47: J6.4, U5.27 (IO47)
IO48: J6.3, U5.30 (IO48)
LIN1: JP2.4, R11.2, U7.1 (LIN1)
LIN2: JP2.5, R12.2, U7.2 (LIN2)
LIN3: JP2.6, U7.3 (LIN3)
LO1: Q4.8 (G2), U7.11 (LO1)
LO2: Q16.8 (G2), U7.10 (LO2)
LO3: Q17.8 (G2), U7.9 (LO3)
unnamed: LED3.A, R27.2
unnamed: LED4.A, R23.2
unnamed: J1.4, Q3.3 (D)
unnamed: J2.B5 (CC2), R3.1
unnamed: LED1.C, LED2.C, LED3.C, LED4.C, LED5.C, S3.1
unnamed: LED2.A, R28.2
unnamed: R19.2, R21.2, U1.3 (EN)
unnamed: C1.1, U1.4 (SS)
unnamed: R20.2, U$1.8 (DAT1)
unnamed: C2.1, C3.1, U1.6 (COMP)
unnamed: C2.2, R22.2
unnamed: Q3.1 (G), R7.2, R8.2
unnamed: LED1.A, R5.2
unnamed: LED5.A, R6.2
unnamed: R24A.1, R24B.2
unnamed: C4.2, U1.1 (BOOT)
unnamed: C15.1, C16.1, D10.C, R19.1, U1.2 (VIN)
unnamed: J2.A5 (CC1), R4.2
PH: C4.1, D9.C, L2.1, U1.8 (PH)
RXD0: J6.1, JP4.1, U5.40 (RXD0)
SD: R1.1, R2.1, R6.1, R16.1, R17.1, R18.1, R20.1, S4.2, U$1.4 (VDD)
TXD0: J6.2, JP4.2, U5.39 (TXD0)
VB1: C51.1, D7.C, U7.20 (VB1)
VB2: C52.1, D8.C, U7.17 (VB2)
VB3: C53.1, D11.C, U7.14 (VB3)
VBUS: D3.A, J2.A4_B9 (VBUS), J2.B4_A9 (VBUS), R27.1
VCC: C7.2, C8.2, C11.2, C12.2, C13.2, C14.2, C27.2, C28.2, C29.2, C30.2, C31.1, C32.1, C33.1, C34.1, C35.1, C36.1, C38.1, C39.1, C40.1, C41.1, C42.1, C43.1, C44.1, C45.1, C46.1, C50.2, C55.1, D7.A, D8.A, D10.A, D11.A, J1.1, J6.12, JP3.1, JP3.2, JP3.3, Q4.2 (D1_1), Q4.3 (D1_2), Q4.4 (D1_3), Q4.9 (D1_4), Q16.2 (D1_1), Q16.3 (D1_2), Q16.4 (D1_3), Q16.9 (D1_4), Q17.2 (D1_1), Q17.3 (D1_2), Q17.4 (D1_3), Q17.9 (D1_4), R23.1, U7.4 (VCC), VCC.1
VS1: A.1, C51.2, Q4.10 (S1/D2), U7.18 (VS1)
VS2: C22.2, C23.2, C52.2, Q16.10 (S1/D2), U7.15 (VS2)
VS3: C.1, C53.2, Q17.10 (S1/D2), U7.12 (VS3)
VSENSE: R24B.1, R25.2, U1.5 (VSENSE)

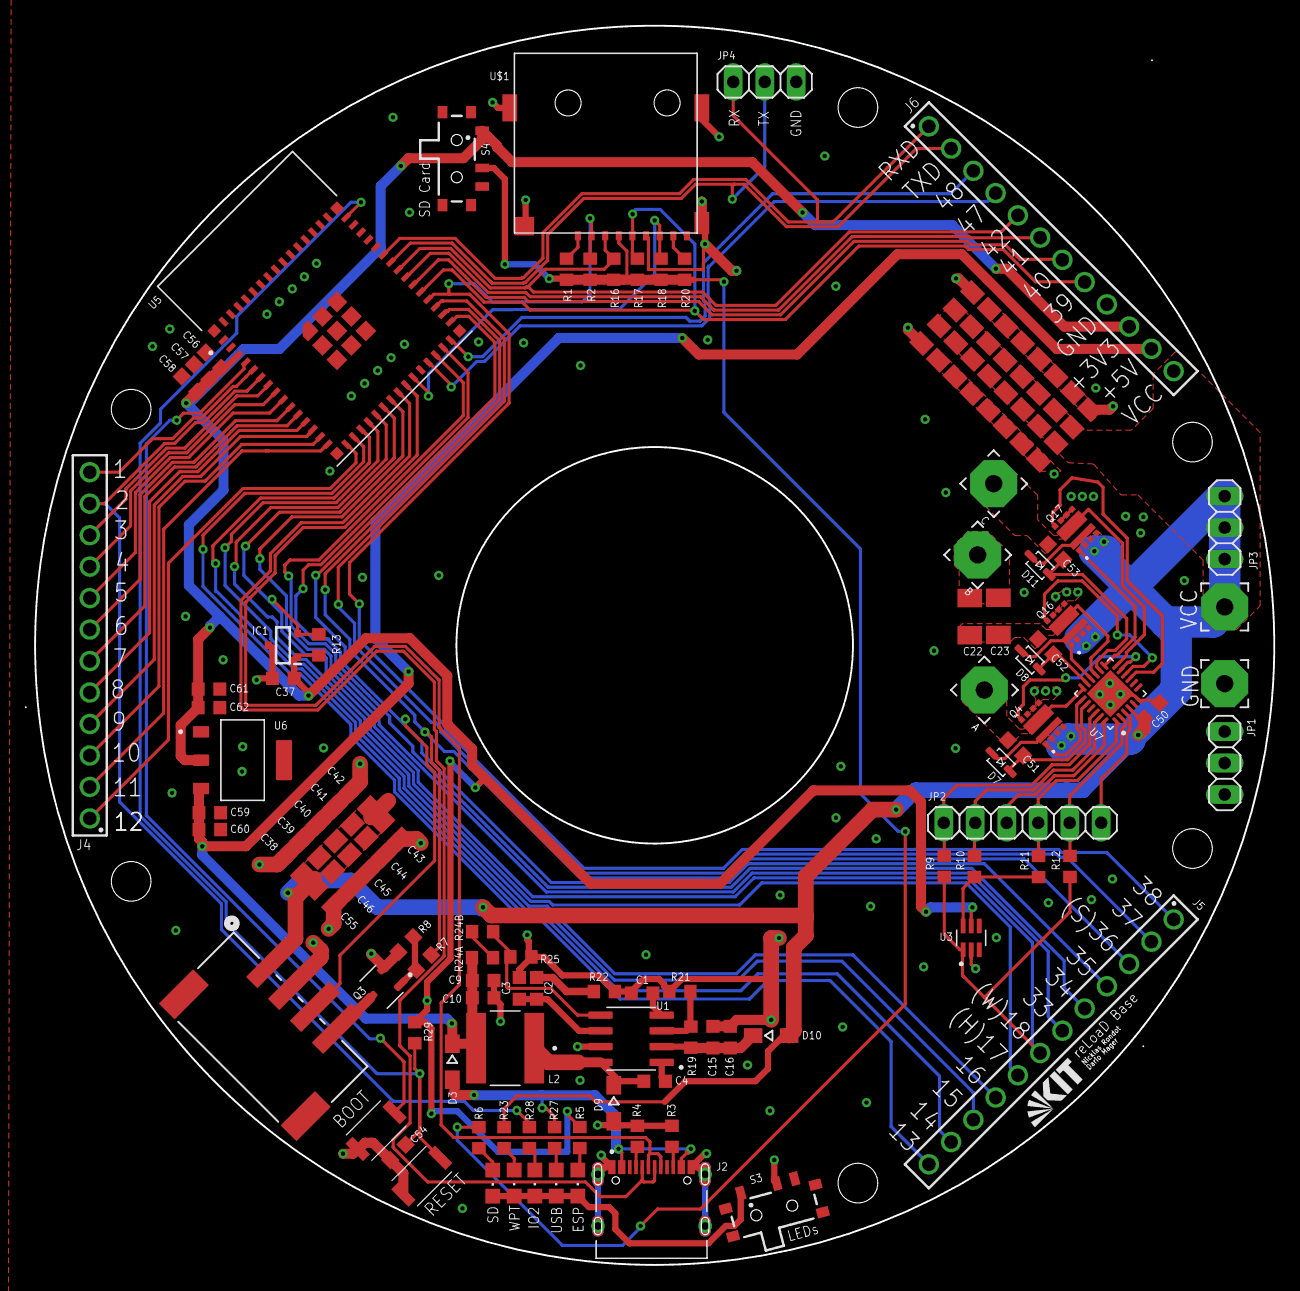
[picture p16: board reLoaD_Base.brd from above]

Board: 2 copper layers, 100.8 x 100.0 mm, 117 parts (0 on the bottom side), 84 nets.

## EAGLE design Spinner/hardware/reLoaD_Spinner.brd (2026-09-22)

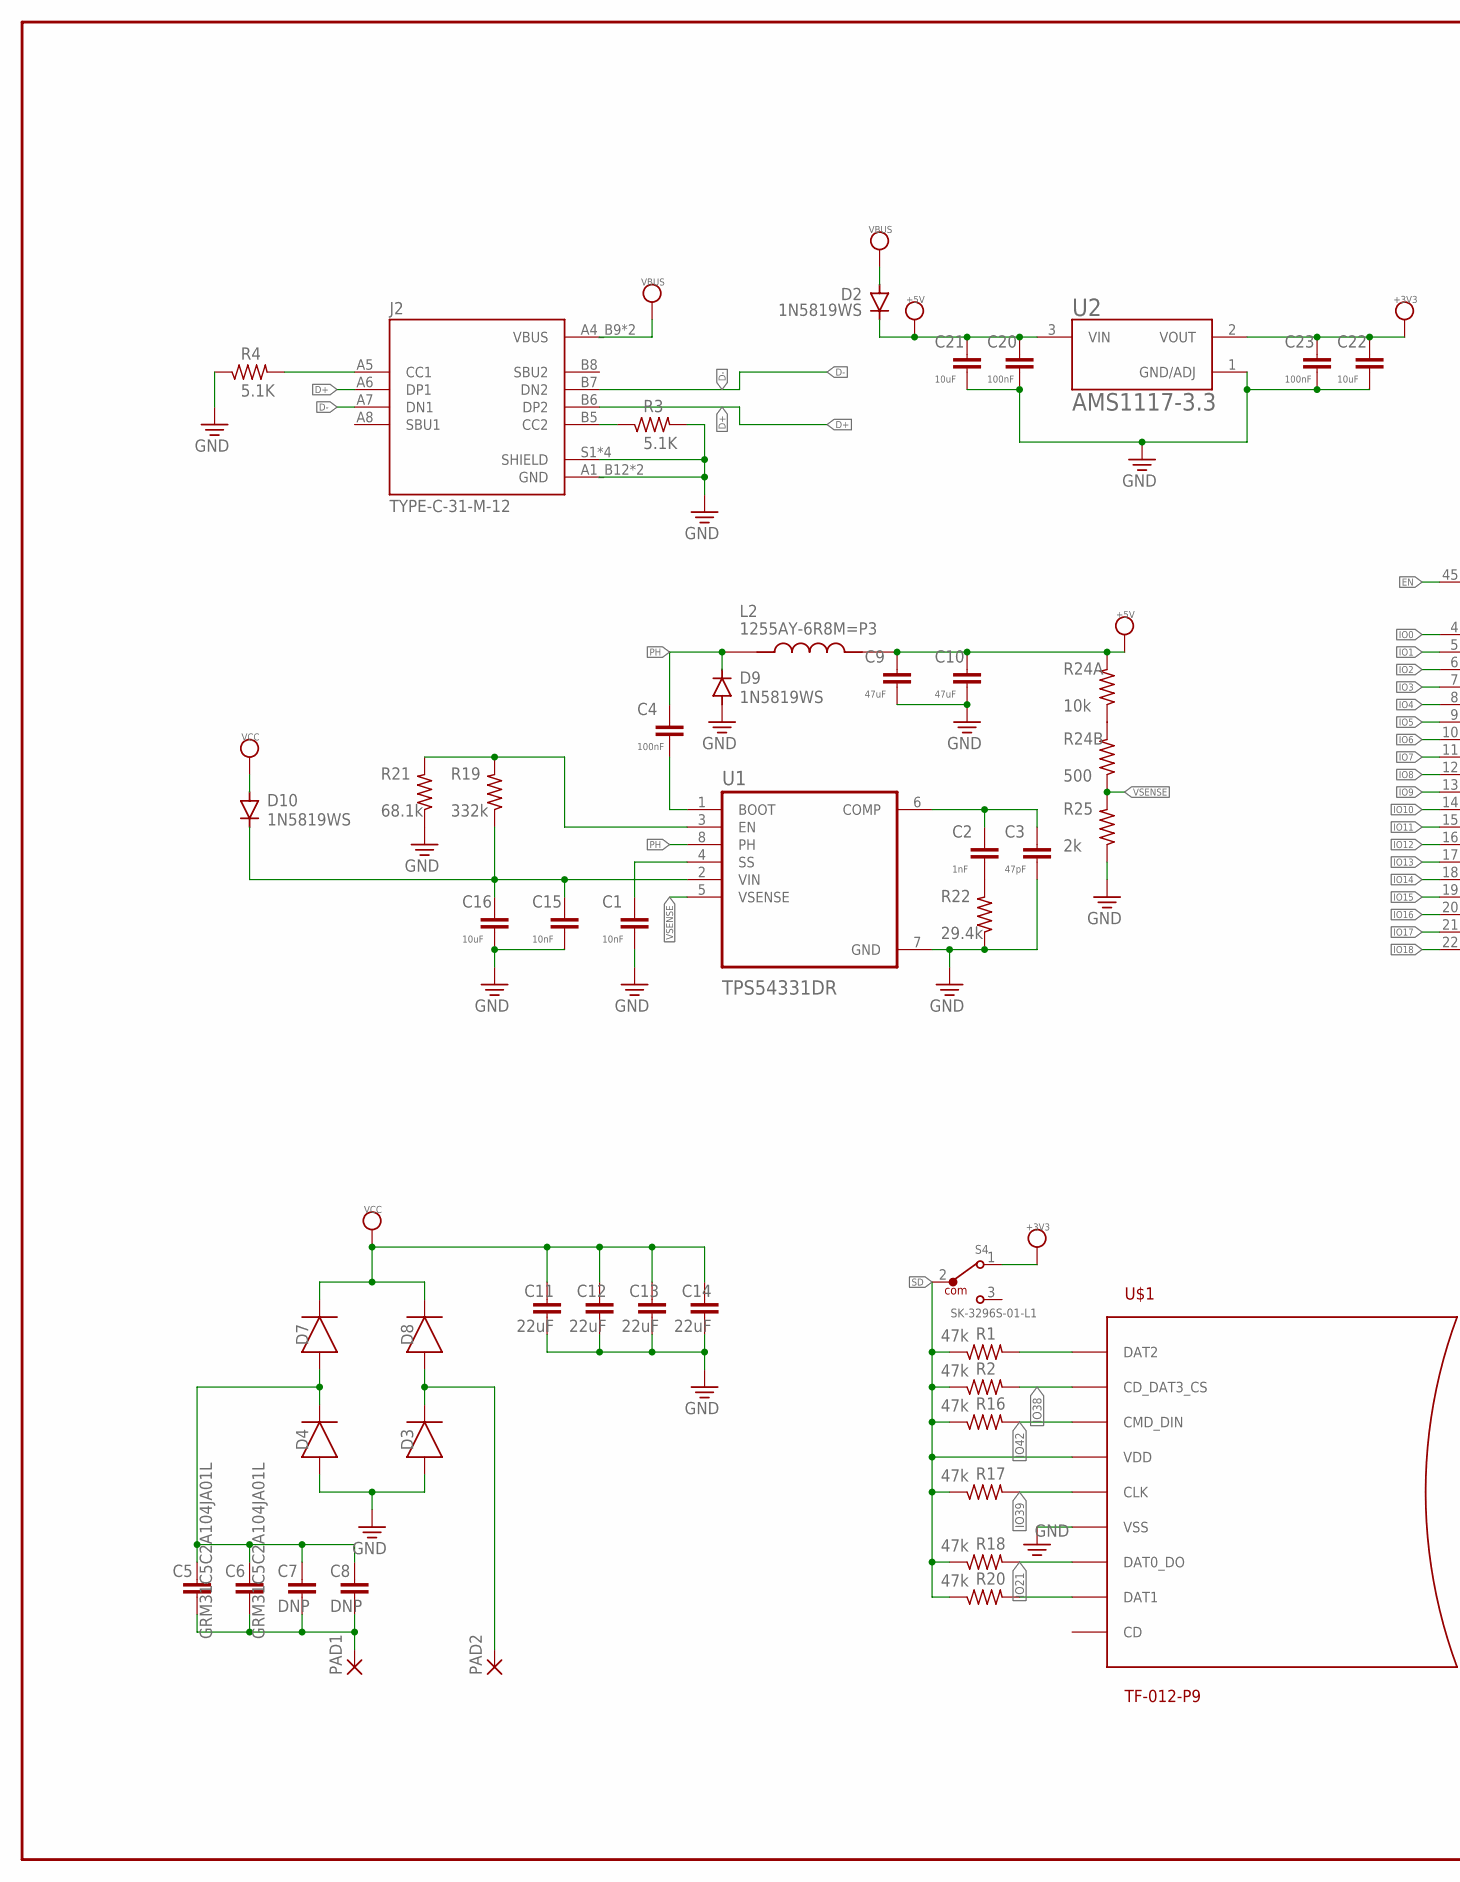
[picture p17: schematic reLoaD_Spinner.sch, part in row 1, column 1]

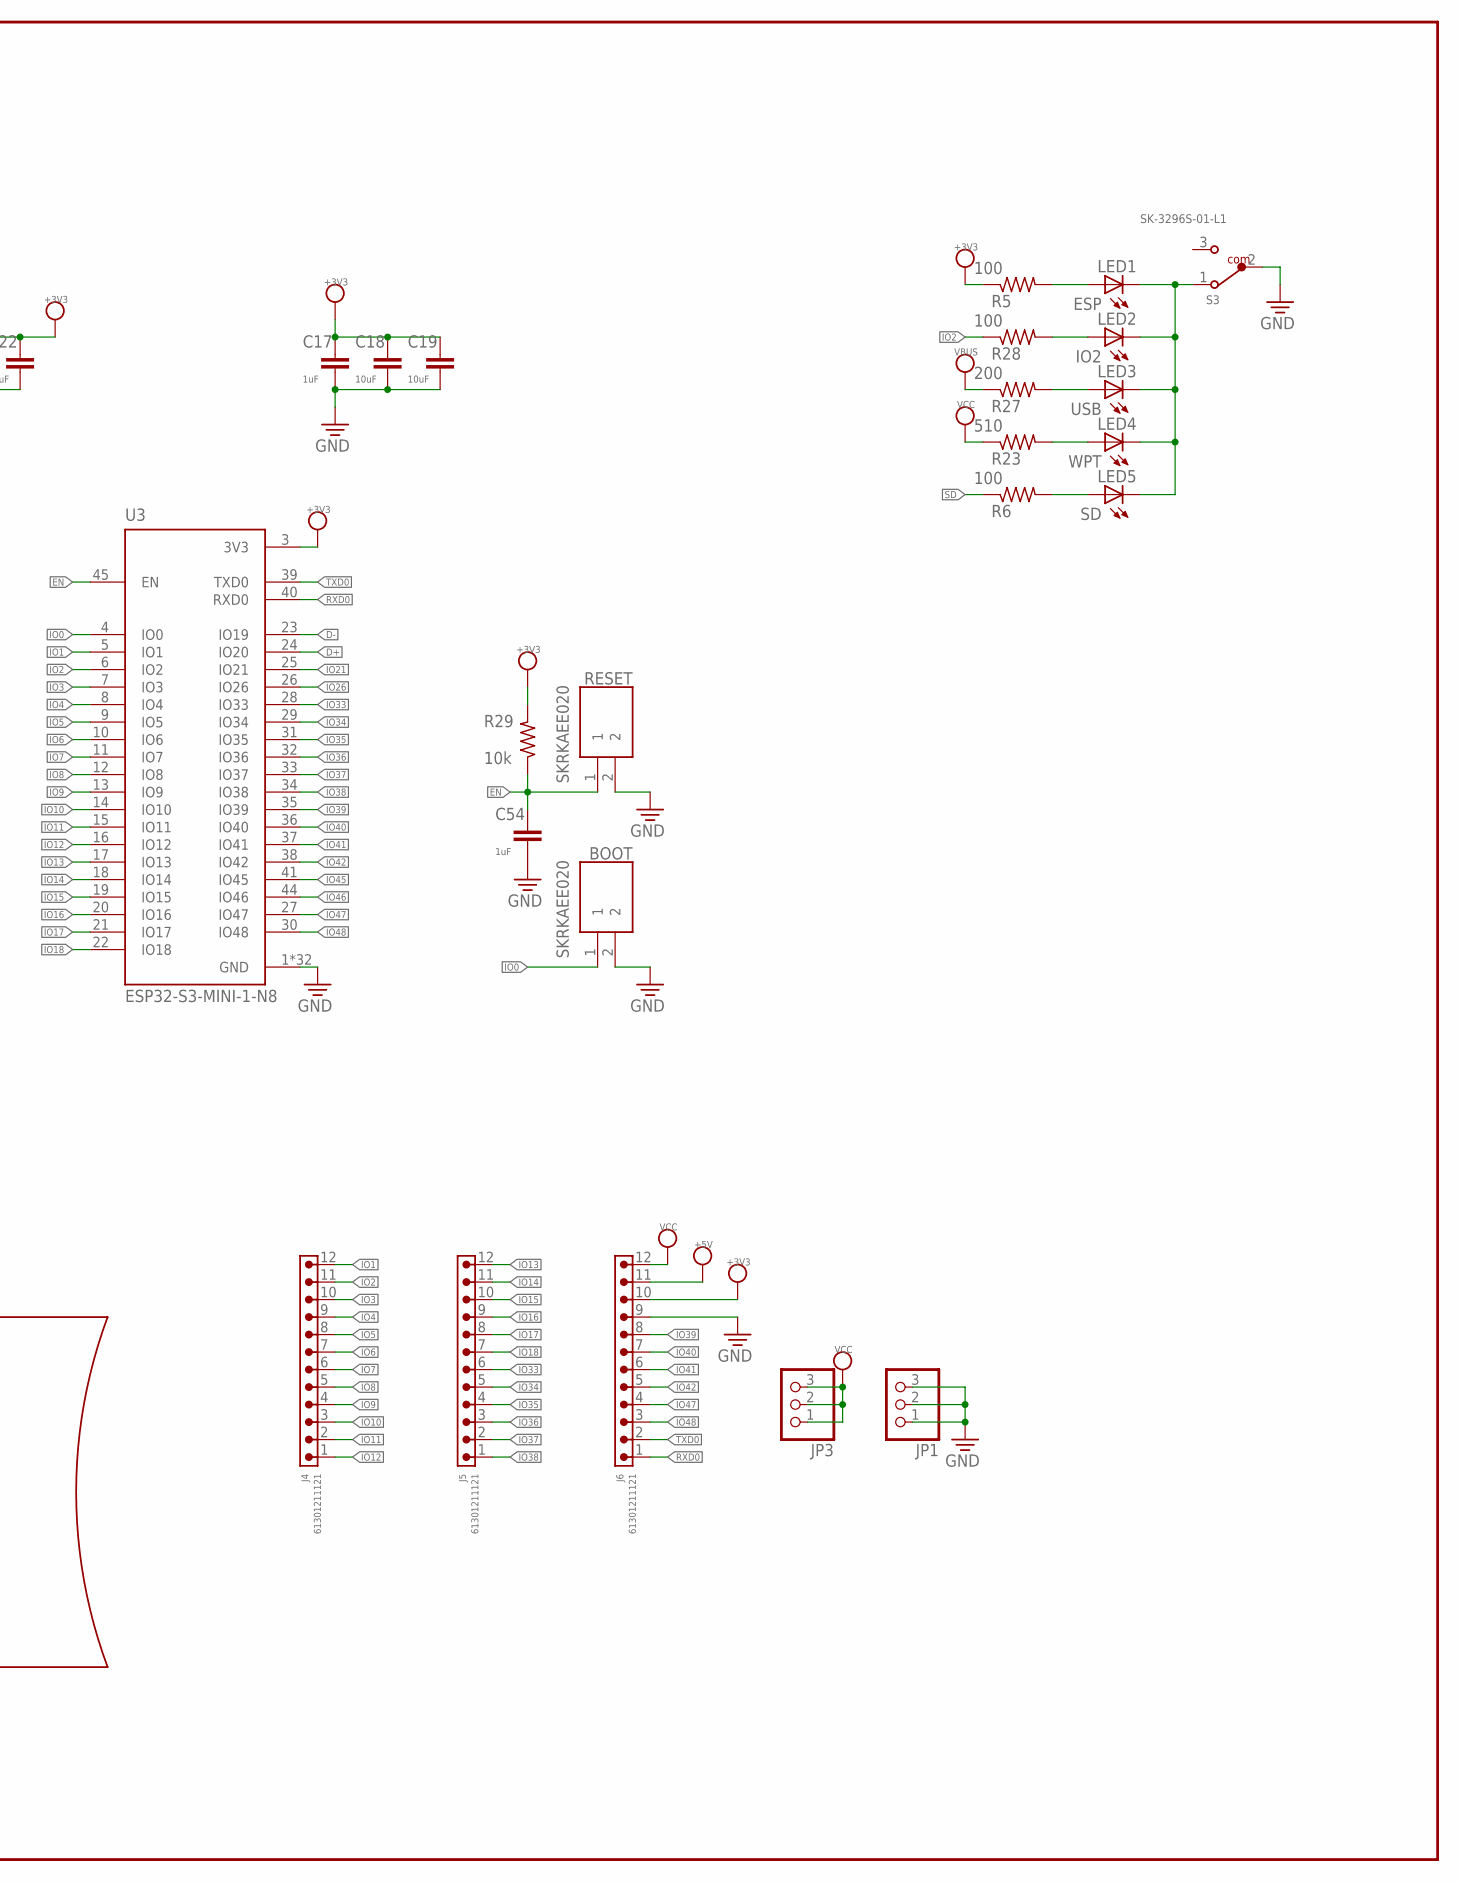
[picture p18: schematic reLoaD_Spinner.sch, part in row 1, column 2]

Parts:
BOOT: SKRKAEE020
C1, C15: 10nF; C0603K
C2: 1nF; C0603K
C3: 47pF; C0603K
C4, C20, C23: 100nF; C0603K
C5, C6: GRM31C5C2A104JA01L; C1206K
C7, C8: DNP; C1206K
C9, C10: 47uF; C0603K
C11, C12, C13, C14: 22uF; C0805K
C16, C18, C19, C21, C22: 10uF; C0603K
C17, C54: 1uF; C0603K
D2, D9, D10: 1N5819WS; SOD323-W
D3, D4, D7, D8: DIODE; DIOM5226X290N
J2: TYPE-C-31-M-12; HRO_TYPE-C-31-M-12
J4, J5, J6: 61301211121
JP1, JP3: PINHD-1X3; 1X03
L2: 1255AY-6R8M=P3; IND_1255AY-6R8M=P3
LED1: ESP; CHIPLED_0805
LED2: IO2; CHIPLED_0805
LED3: USB; CHIPLED_0805
LED4: WPT; CHIPLED_0805
LED5: SD; CHIPLED_0805
PAD1, PAD2: 3,81/1,4
R1, R2, R16, R17, R18, R20: 47k; R0603
R3, R4: 5.1K; R0603
R5, R6, R28: 100; R0603
R19: 332k; R0603
R21: 68.1k; R0603
R22: 29.4k; R0603
R23: 510; R0603
R24A, R29: 10k; R0603
R24B: 500; R0603
R25: 2k; R0603
R27: 200; R0603
RESET: SKRKAEE020
S3, S4: SK-3296S-01-L1; 450404015514
U1: TPS54331DR; SOIC127P599X175-8N
U2: AMS1117-3.3; SOT229P700X180-4N
U3: ESP32-S3-MINI-1-N8; XCVR_ESP32-S3-MINI-1-N8
U$1: TF-012-P9; MICROSD-PUSH-OUT

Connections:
+3V3: C17.1, C18.1, C19.1, C22.1, C23.1, J6.10, R5.1, R29.2, S4.1, U2.2 (VOUT), U3.3 (3V3)
+5V: C9.1, C10.1, C20.1, C21.1, D2.C, J6.11, L2.2, R24A.2, U2.3 (VIN)
COIL1: C5.2, C6.2, C7.2, C8.2, PAD1.1
COIL2: D3.1 (C), D8.2 (A), PAD2.1
D+: J2.A6 (DP1), J2.B6 (DP2), U3.24 (IO20)
D-: J2.A7 (DN1), J2.B7 (DN2), U3.23 (IO19)
DAT2: R1.2, U$1.1 (DAT2)
EN: C54.1, R29.1, RESET.1, U3.45 (EN)
GND: BOOT.2, C1.2, C3.2, C9.2, C10.2, C11.1, C12.1, C13.1, C14.1, C15.2, C16.2, C17.2, C18.2, C19.2, C20.2, C21.2, C22.2, C23.2, C54.2, D3.2 (A), D4.2 (A), D9.A, J2.A1_B12 (GND), J2.B1_A12 (GND), J2.S1 (SHIELD), J2.S2 (SHIELD), J2.S3 (SHIELD), J2.S4 (SHIELD), J6.9, JP1.1, JP1.2, JP1.3, R3.2, R4.1, R21.1, R22.1, R25.1, RESET.2, S3.2, U1.7 (GND), U2.1 (GND/ADJ), U3.1 (GND), U3.2 (GND), U3.42 (GND), U3.43 (GND), U3.46 (GND), U3.47 (GND), U3.48 (GND), U3.49 (GND), U3.50 (GND), U3.51 (GND), U3.52 (GND), U3.53 (GND), U3.54 (GND), U3.55 (GND), U3.56 (GND), U3.57 (GND), U3.58 (GND), U3.59 (GND), U3.60 (GND), U3.61 (GND), U3.61_1 (GND), U3.61_2 (GND), U3.61_3 (GND), U3.61_4 (GND), U3.61_5 (GND), U3.61_6 (GND), U3.61_7 (GND), U3.61_8 (GND), U3.62 (GND), U3.63 (GND), U3.64 (GND), U3.65 (GND), U$1.6 (VSS), U$1.G1 (VSS), U$1.G2 (VSS), U$1.G3 (VSS), U$1.G4 (VSS)
IO0: BOOT.1, U3.4 (IO0)
IO1: J4.12, U3.5 (IO1)
IO2: J4.11, R28.1, U3.6 (IO2)
IO3: J4.10, U3.7 (IO3)
IO4: J4.9, U3.8 (IO4)
IO5: J4.8, U3.9 (IO5)
IO6: J4.7, U3.10 (IO6)
IO7: J4.6, U3.11 (IO7)
IO8: J4.5, U3.12 (IO8)
IO9: J4.4, U3.13 (IO9)
IO10: J4.3, U3.14 (IO10)
IO11: J4.2, U3.15 (IO11)
IO12: J4.1, U3.16 (IO12)
IO13: J5.12, U3.17 (IO13)
IO14: J5.11, U3.18 (IO14)
IO15: J5.10, U3.19 (IO15)
IO16: J5.9, U3.20 (IO16)
IO17: J5.8, U3.21 (IO17)
IO18: J5.7, U3.22 (IO18)
IO21: R18.2, U3.25 (IO21), U$1.7 (DAT0_DO)
IO26: U3.26 (IO26)
IO33: J5.6, U3.28 (IO33)
IO34: J5.5, U3.29 (IO34)
IO35: J5.4, U3.31 (IO35)
IO36: J5.3, U3.32 (IO36)
IO37: J5.2, U3.33 (IO37)
IO38: J5.1, R2.2, U3.34 (IO38), U$1.2 (CD_DAT3_CS)
IO39: J6.8, R17.2, U3.35 (IO39), U$1.5 (CLK)
IO40: J6.7, U3.36 (IO40)
IO41: J6.6, U3.37 (IO41)
IO42: J6.5, R16.2, U3.38 (IO42), U$1.3 (CMD_DIN)
IO45: U3.41 (IO45)
IO46: U3.44 (IO46)
IO47: J6.4, U3.27 (IO47)
IO48: J6.3, U3.30 (IO48)
unnamed: LED3.A, R27.2
unnamed: LED4.A, R23.2
unnamed: J2.B5 (CC2), R3.1
unnamed: LED1.C, LED2.C, LED3.C, LED4.C, LED5.C, S3.1
unnamed: LED2.A, R28.2
unnamed: R19.2, R21.2, U1.3 (EN)
unnamed: C1.1, U1.4 (SS)
unnamed: R20.2, U$1.8 (DAT1)
unnamed: C2.1, C3.1, U1.6 (COMP)
unnamed: C2.2, R22.2
unnamed: LED5.A, R6.2
unnamed: LED1.A, R5.2
unnamed: R24A.1, R24B.2
unnamed: C5.1, C6.1, C7.1, C8.1, D4.1 (C), D7.2 (A)
unnamed: C4.2, U1.1 (BOOT)
unnamed: C15.1, C16.1, D10.C, R19.1, U1.2 (VIN)
unnamed: J2.A5 (CC1), R4.2
PH: C4.1, D9.C, L2.1, U1.8 (PH)
RXD0: J6.1, U3.40 (RXD0)
SD: R1.1, R2.1, R6.1, R16.1, R17.1, R18.1, R20.1, S4.2, U$1.4 (VDD)
TXD0: J6.2, U3.39 (TXD0)
VBUS: D2.A, J2.A4_B9 (VBUS), J2.B4_A9 (VBUS), R27.1
VCC: C11.2, C12.2, C13.2, C14.2, D7.1 (C), D8.1 (C), D10.A, J6.12, JP3.1, JP3.2, JP3.3, R23.1
VSENSE: R24B.1, R25.2, U1.5 (VSENSE)

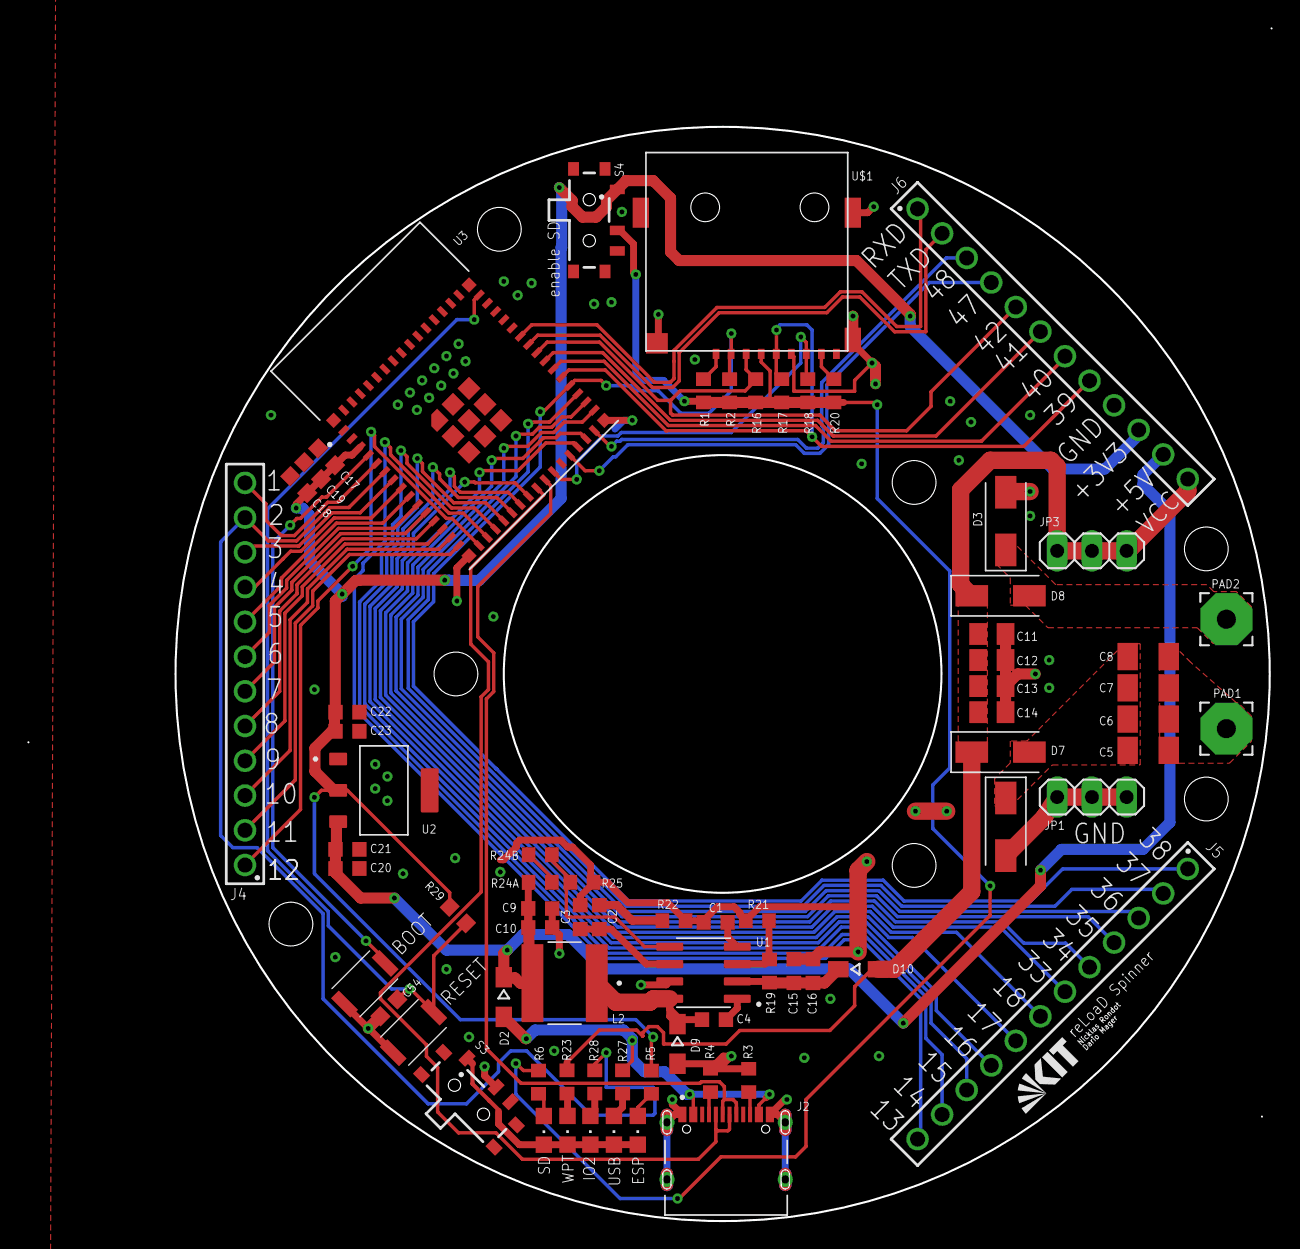
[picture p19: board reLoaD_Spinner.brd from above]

Board: 2 copper layers, 80.0 x 80.0 mm, 73 parts (0 on the bottom side), 65 nets.

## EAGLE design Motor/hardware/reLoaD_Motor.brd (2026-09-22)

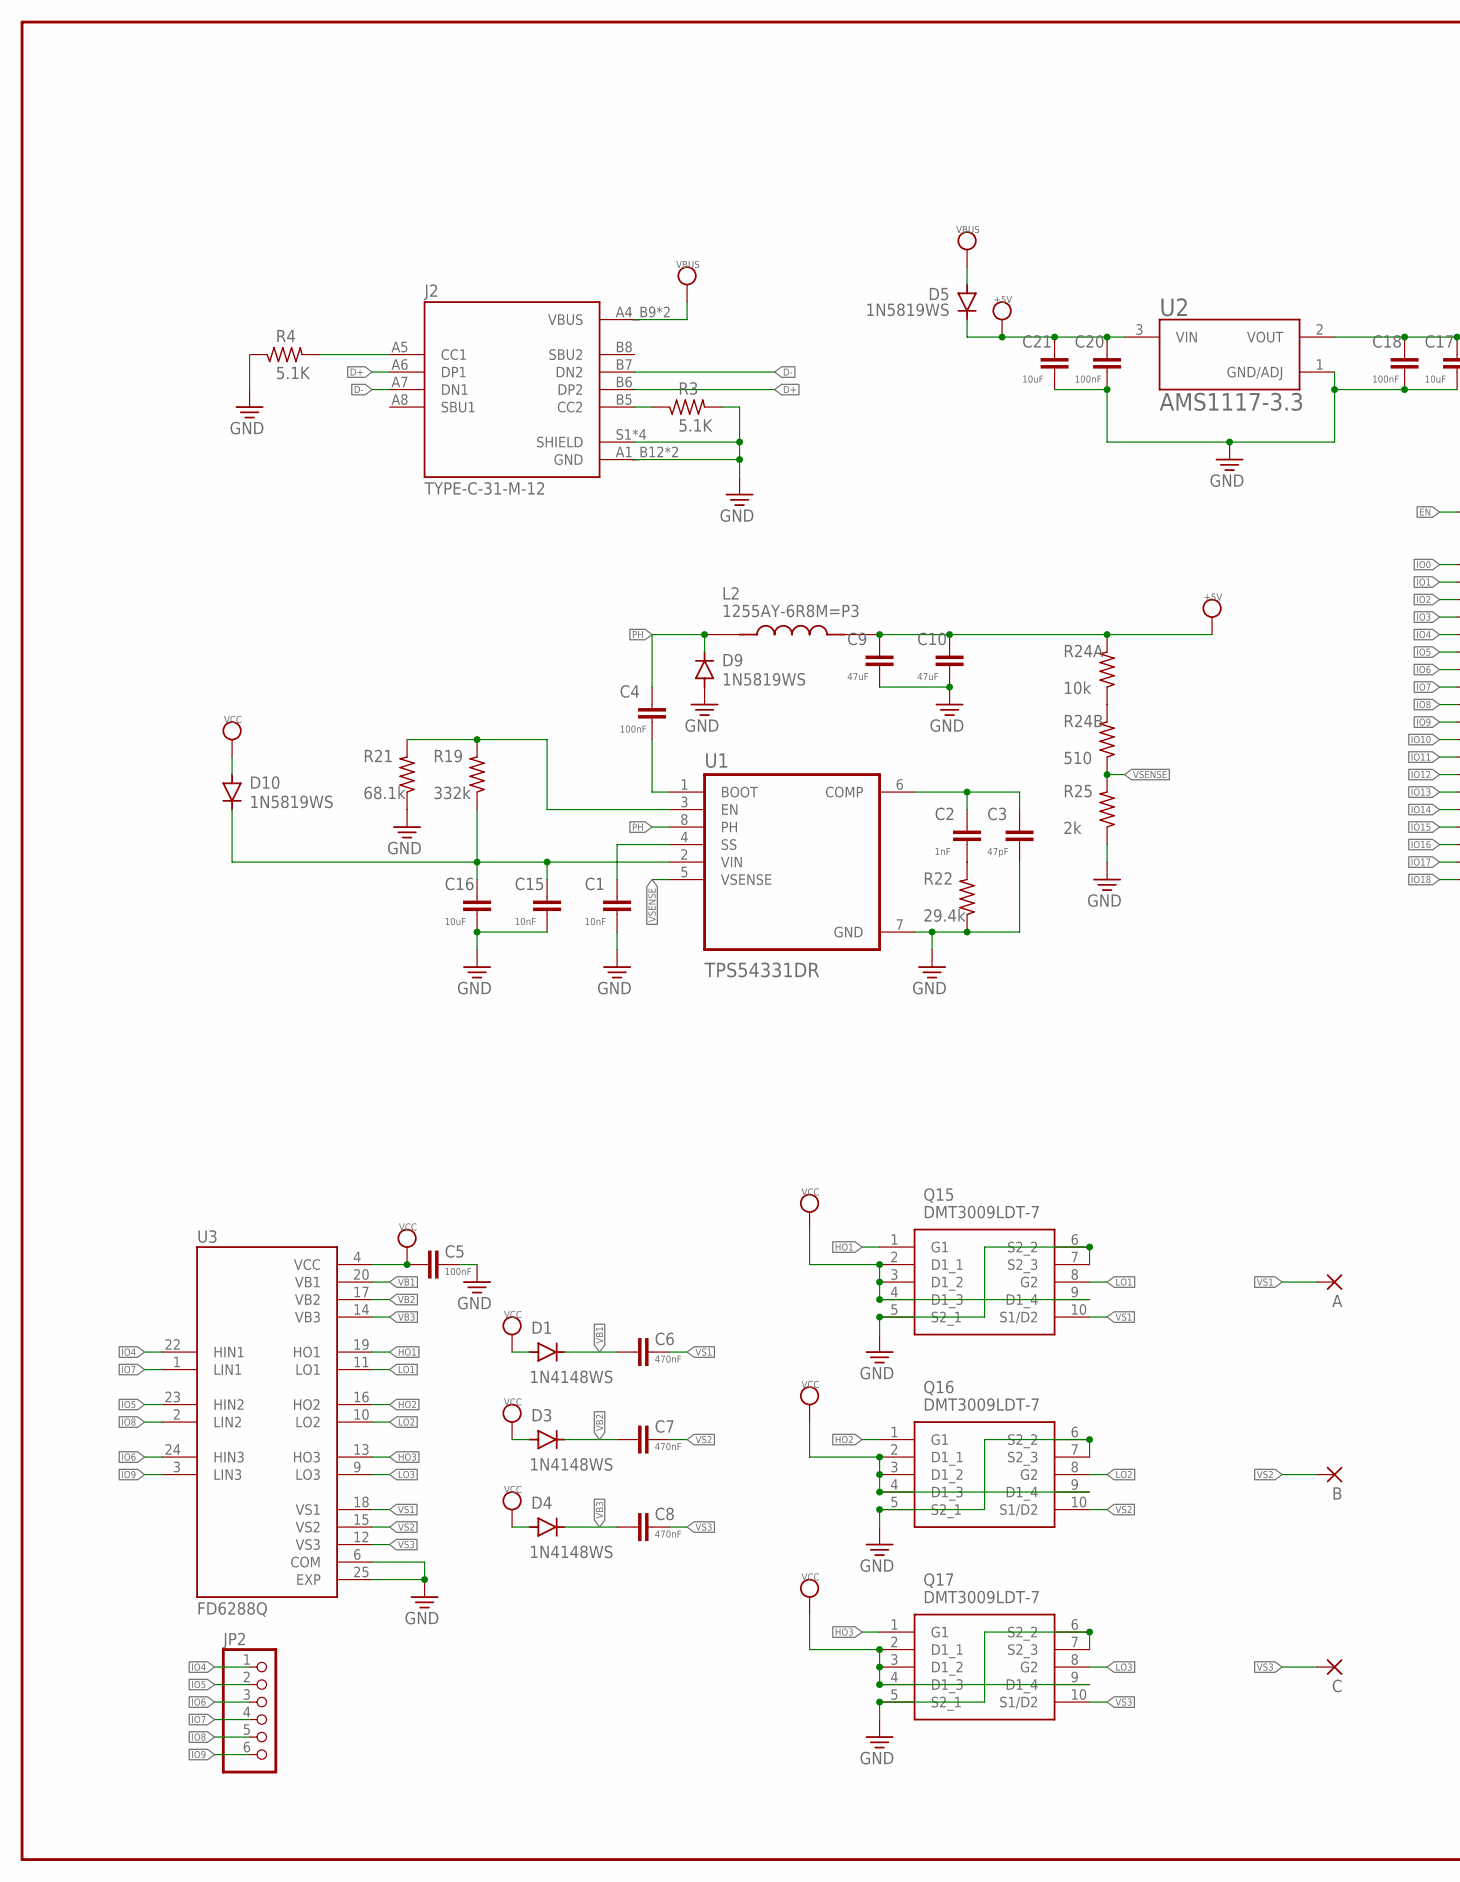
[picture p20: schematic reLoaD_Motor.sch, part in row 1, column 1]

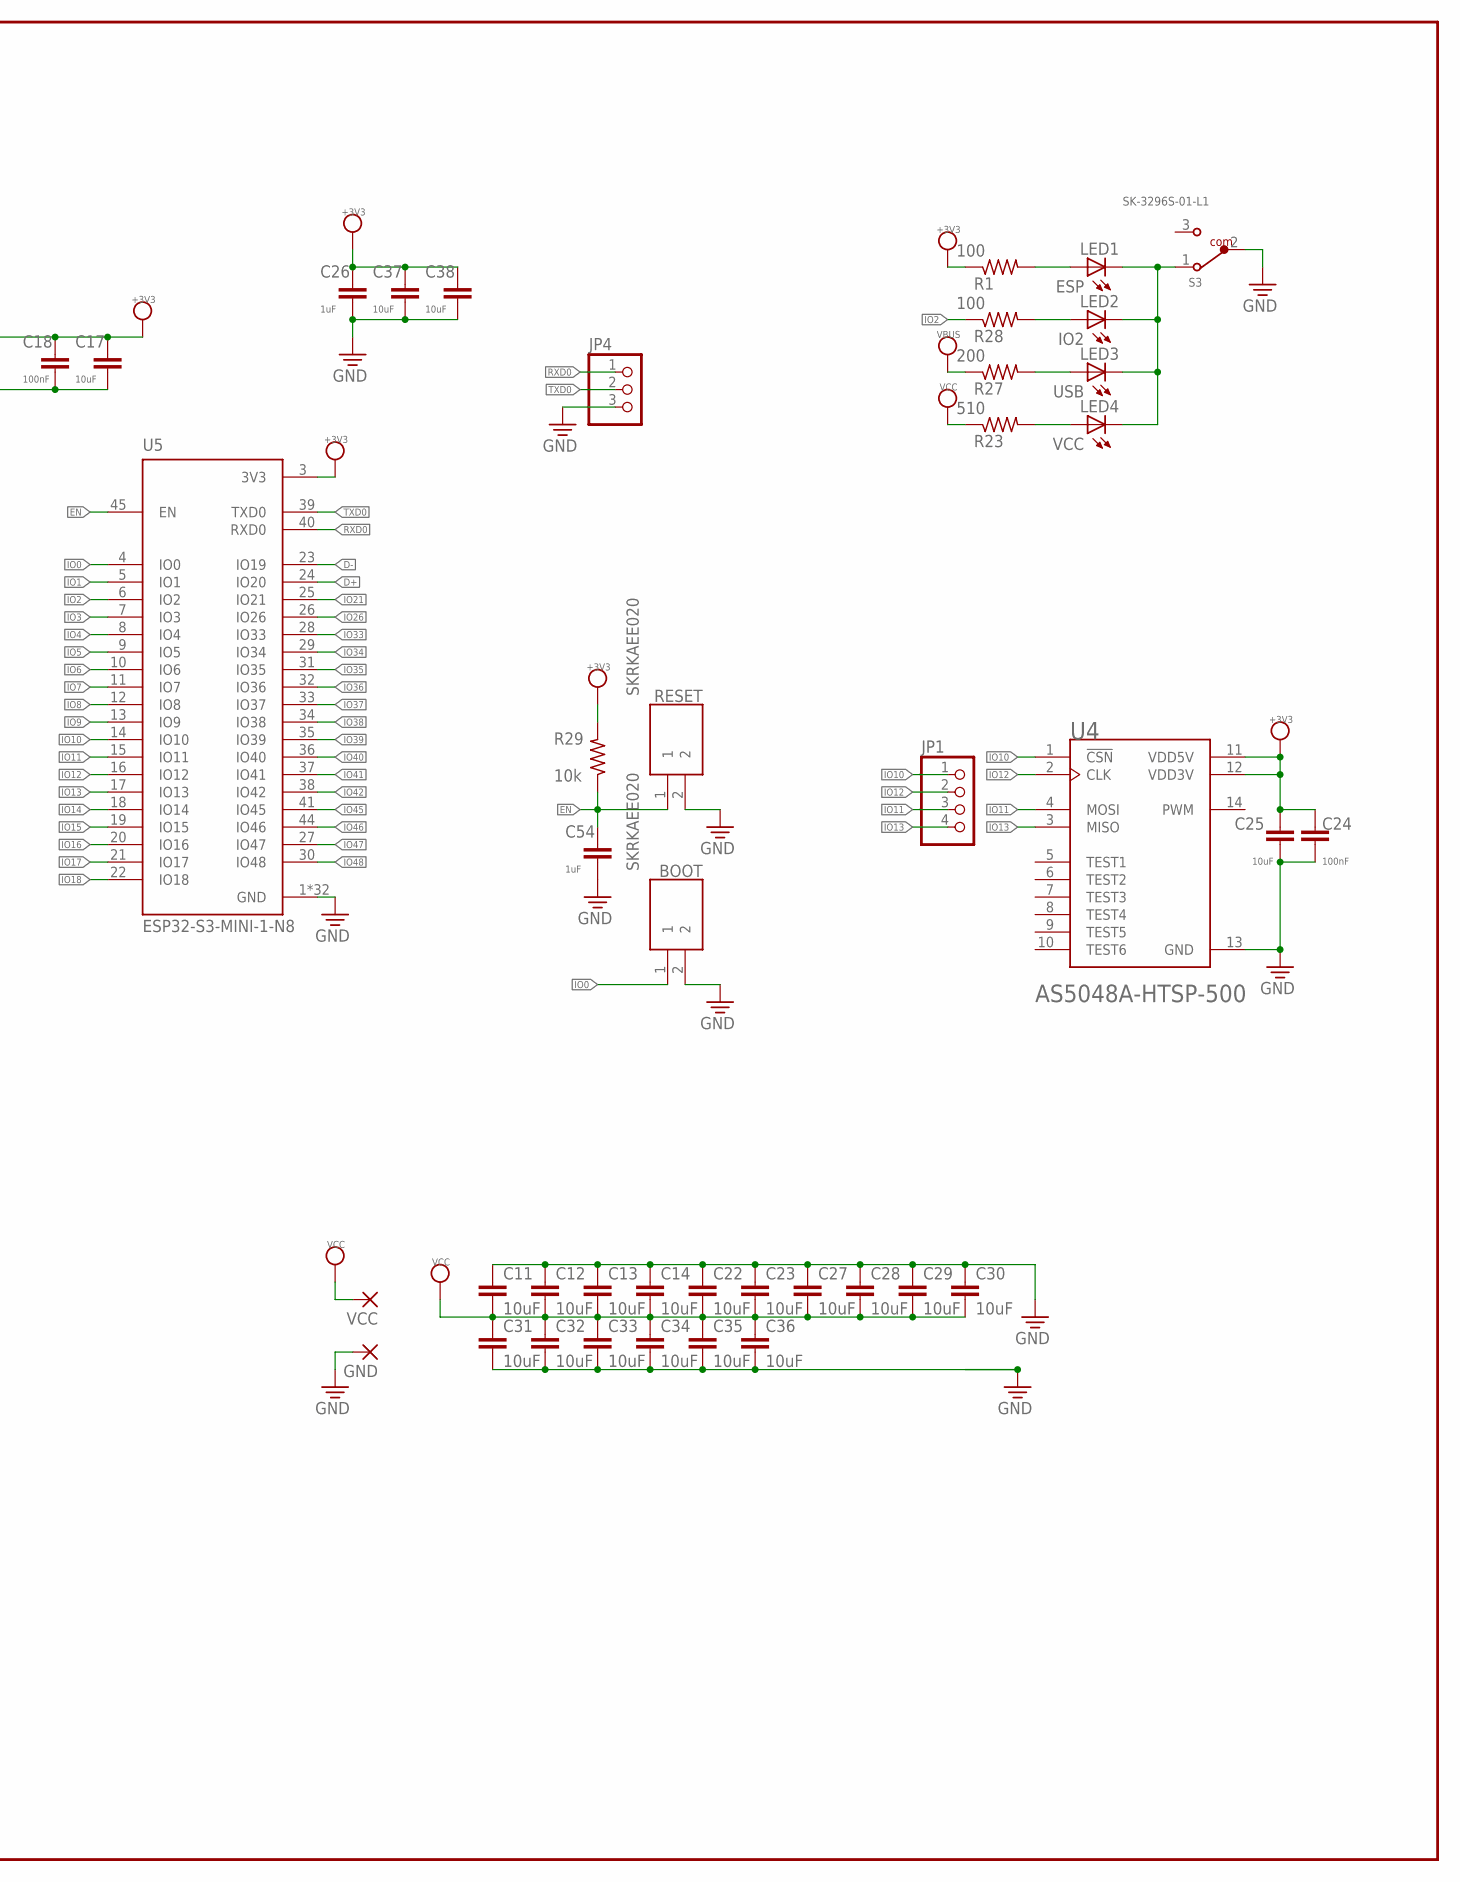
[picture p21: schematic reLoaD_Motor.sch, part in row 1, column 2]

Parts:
A: 3,81/1,4
B: 3,81/1,4
BOOT: SKRKAEE020
C: 3,81/1,4
C1, C15: 10nF; C0603K
C2: 1nF; C0603K
C3: 47pF; C0603K
C4, C5, C18, C20, C24: 100nF; C0603K
C6, C7, C8: 470nF; C0603K
C9, C10: 47uF; C0603K
C11, C12, C13, C14, C22, C23, C27, C28, C29, C30, C31, C32, C33, C34, C35, C36: 10uF; C0805K
C16, C17, C21, C25, C37, C38: 10uF; C0603K
C26, C54: 1uF; C0603K
D1, D3, D4: 1N4148WS; SOD-323
D5, D9, D10: 1N5819WS; SOD323-W
GND: 3,81/1,4
J2: TYPE-C-31-M-12; HRO_TYPE-C-31-M-12
JP1: PINHD-1X4; 1X04
JP2: PINHD-1X6; 1X06
JP4: PINHD-1X3; 1X03
L2: 1255AY-6R8M=P3; IND_1255AY-6R8M=P3
LED1: ESP; CHIPLED_0805
LED2: IO2; CHIPLED_0805
LED3: USB; CHIPLED_0805
LED4: VCC; CHIPLED_0805
Q15, Q16, Q17: DMT3009LDT-7; DMT3009LDT7
R1, R28: 100; R0603
R3, R4: 5.1K; R0603
R19: 332k; R0603
R21: 68.1k; R0603
R22: 29.4k; R0603
R23, R24B: 510; R0603
R24A, R29: 10k; R0603
R25: 2k; R0603
R27: 200; R0603
RESET: SKRKAEE020
S3: SK-3296S-01-L1; 450404015514
U1: TPS54331DR; SOIC127P599X175-8N
U2: AMS1117-3.3; SOT229P700X180-4N
U3: FD6288Q; QFN50P400X400X90-25N
U4: AS5048A-HTSP-500; SOP65P640X120-14N
U5: ESP32-S3-MINI-1-N8; XCVR_ESP32-S3-MINI-1-N8
VCC: 3,81/1,4

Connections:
+3V3: C17.1, C18.1, C24.2, C25.2, C26.1, C37.1, C38.1, R1.1, R29.2, U2.2 (VOUT), U4.11 (VDD5V), U4.12 (VDD3V), U5.3 (3V3)
+5V: C9.1, C10.1, C20.1, C21.1, D5.C, L2.2, R24A.2, U2.3 (VIN)
D+: J2.A6 (DP1), J2.B6 (DP2), U5.24 (IO20)
D-: J2.A7 (DN1), J2.B7 (DN2), U5.23 (IO19)
EN: C54.1, R29.1, RESET.1, U5.45 (EN)
GND: BOOT.2, C1.2, C3.2, C5.1, C9.2, C10.2, C11.1, C12.1, C13.1, C14.1, C15.2, C16.2, C17.2, C18.2, C20.2, C21.2, C22.1, C23.1, C24.1, C25.1, C26.2, C27.1, C28.1, C29.1, C30.1, C31.2, C32.2, C33.2, C34.2, C35.2, C36.2, C37.2, C38.2, C54.2, D9.A, GND.1, J2.A1_B12 (GND), J2.B1_A12 (GND), J2.S1 (SHIELD), J2.S2 (SHIELD), J2.S3 (SHIELD), J2.S4 (SHIELD), JP4.3, Q15.5 (S2_1), Q15.6 (S2_2), Q15.7 (S2_3), Q16.5 (S2_1), Q16.6 (S2_2), Q16.7 (S2_3), Q17.5 (S2_1), Q17.6 (S2_2), Q17.7 (S2_3), R3.2, R4.1, R21.1, R22.1, R25.1, RESET.2, S3.2, U1.7 (GND), U2.1 (GND/ADJ), U3.6 (COM), U3.25 (EXP), U4.13 (GND), U5.1 (GND), U5.2 (GND), U5.42 (GND), U5.43 (GND), U5.46 (GND), U5.47 (GND), U5.48 (GND), U5.49 (GND), U5.50 (GND), U5.51 (GND), U5.52 (GND), U5.53 (GND), U5.54 (GND), U5.55 (GND), U5.56 (GND), U5.57 (GND), U5.58 (GND), U5.59 (GND), U5.60 (GND), U5.61 (GND), U5.61_1 (GND), U5.61_2 (GND), U5.61_3 (GND), U5.61_4 (GND), U5.61_5 (GND), U5.61_6 (GND), U5.61_7 (GND), U5.61_8 (GND), U5.62 (GND), U5.63 (GND), U5.64 (GND), U5.65 (GND)
HO1: Q15.1 (G1), U3.19 (HO1)
HO2: Q16.1 (G1), U3.16 (HO2)
HO3: Q17.1 (G1), U3.13 (HO3)
IO0: BOOT.1, U5.4 (IO0)
IO1: U5.5 (IO1)
IO2: R28.1, U5.6 (IO2)
IO3: U5.7 (IO3)
IO4: JP2.1, U3.22 (HIN1), U5.8 (IO4)
IO5: JP2.2, U3.23 (HIN2), U5.9 (IO5)
IO6: JP2.3, U3.24 (HIN3), U5.10 (IO6)
IO7: JP2.4, U3.1 (LIN1), U5.11 (IO7)
IO8: JP2.5, U3.2 (LIN2), U5.12 (IO8)
IO9: JP2.6, U3.3 (LIN3), U5.13 (IO9)
IO10: JP1.1, U4.1 (!CSN), U5.14 (IO10)
IO11: JP1.3, U4.4 (MOSI), U5.15 (IO11)
IO12: JP1.2, U4.2 (CLK), U5.16 (IO12)
IO13: JP1.4, U4.3 (MISO), U5.17 (IO13)
IO14: U5.18 (IO14)
IO15: U5.19 (IO15)
IO16: U5.20 (IO16)
IO17: U5.21 (IO17)
IO18: U5.22 (IO18)
IO21: U5.25 (IO21)
IO26: U5.26 (IO26)
IO33: U5.28 (IO33)
IO34: U5.29 (IO34)
IO35: U5.31 (IO35)
IO36: U5.32 (IO36)
IO37: U5.33 (IO37)
IO38: U5.34 (IO38)
IO39: U5.35 (IO39)
IO40: U5.36 (IO40)
IO41: U5.37 (IO41)
IO42: U5.38 (IO42)
IO45: U5.41 (IO45)
IO46: U5.44 (IO46)
IO47: U5.27 (IO47)
IO48: U5.30 (IO48)
LO1: Q15.8 (G2), U3.11 (LO1)
LO2: Q16.8 (G2), U3.10 (LO2)
LO3: Q17.8 (G2), U3.9 (LO3)
unnamed: LED3.A, R27.2
unnamed: LED4.A, R23.2
unnamed: LED1.A, R1.2
unnamed: J2.B5 (CC2), R3.1
unnamed: LED1.C, LED2.C, LED3.C, LED4.C, S3.1
unnamed: LED2.A, R28.2
unnamed: R19.2, R21.2, U1.3 (EN)
unnamed: C1.1, U1.4 (SS)
unnamed: R24A.1, R24B.2
unnamed: C2.1, C3.1, U1.6 (COMP)
unnamed: C2.2, R22.2
unnamed: C4.2, U1.1 (BOOT)
unnamed: C15.1, C16.1, D10.C, R19.1, U1.2 (VIN)
unnamed: J2.A5 (CC1), R4.2
PH: C4.1, D9.C, L2.1, U1.8 (PH)
RXD0: JP4.1, U5.40 (RXD0)
TXD0: JP4.2, U5.39 (TXD0)
VB1: C6.1, D1.C, U3.20 (VB1)
VB2: C7.1, D3.C, U3.17 (VB2)
VB3: C8.1, D4.C, U3.14 (VB3)
VBUS: D5.A, J2.A4_B9 (VBUS), J2.B4_A9 (VBUS), R27.1
VCC: C5.2, C11.2, C12.2, C13.2, C14.2, C22.2, C23.2, C27.2, C28.2, C29.2, C30.2, C31.1, C32.1, C33.1, C34.1, C35.1, C36.1, D1.A, D3.A, D4.A, D10.A, Q15.2 (D1_1), Q15.3 (D1_2), Q15.4 (D1_3), Q15.9 (D1_4), Q16.2 (D1_1), Q16.3 (D1_2), Q16.4 (D1_3), Q16.9 (D1_4), Q17.2 (D1_1), Q17.3 (D1_2), Q17.4 (D1_3), Q17.9 (D1_4), R23.1, U3.4 (VCC), VCC.1
VS1: A.1, C6.2, Q15.10 (S1/D2), U3.18 (VS1)
VS2: B.1, C7.2, Q16.10 (S1/D2), U3.15 (VS2)
VS3: C.1, C8.2, Q17.10 (S1/D2), U3.12 (VS3)
VSENSE: R24B.1, R25.2, U1.5 (VSENSE)

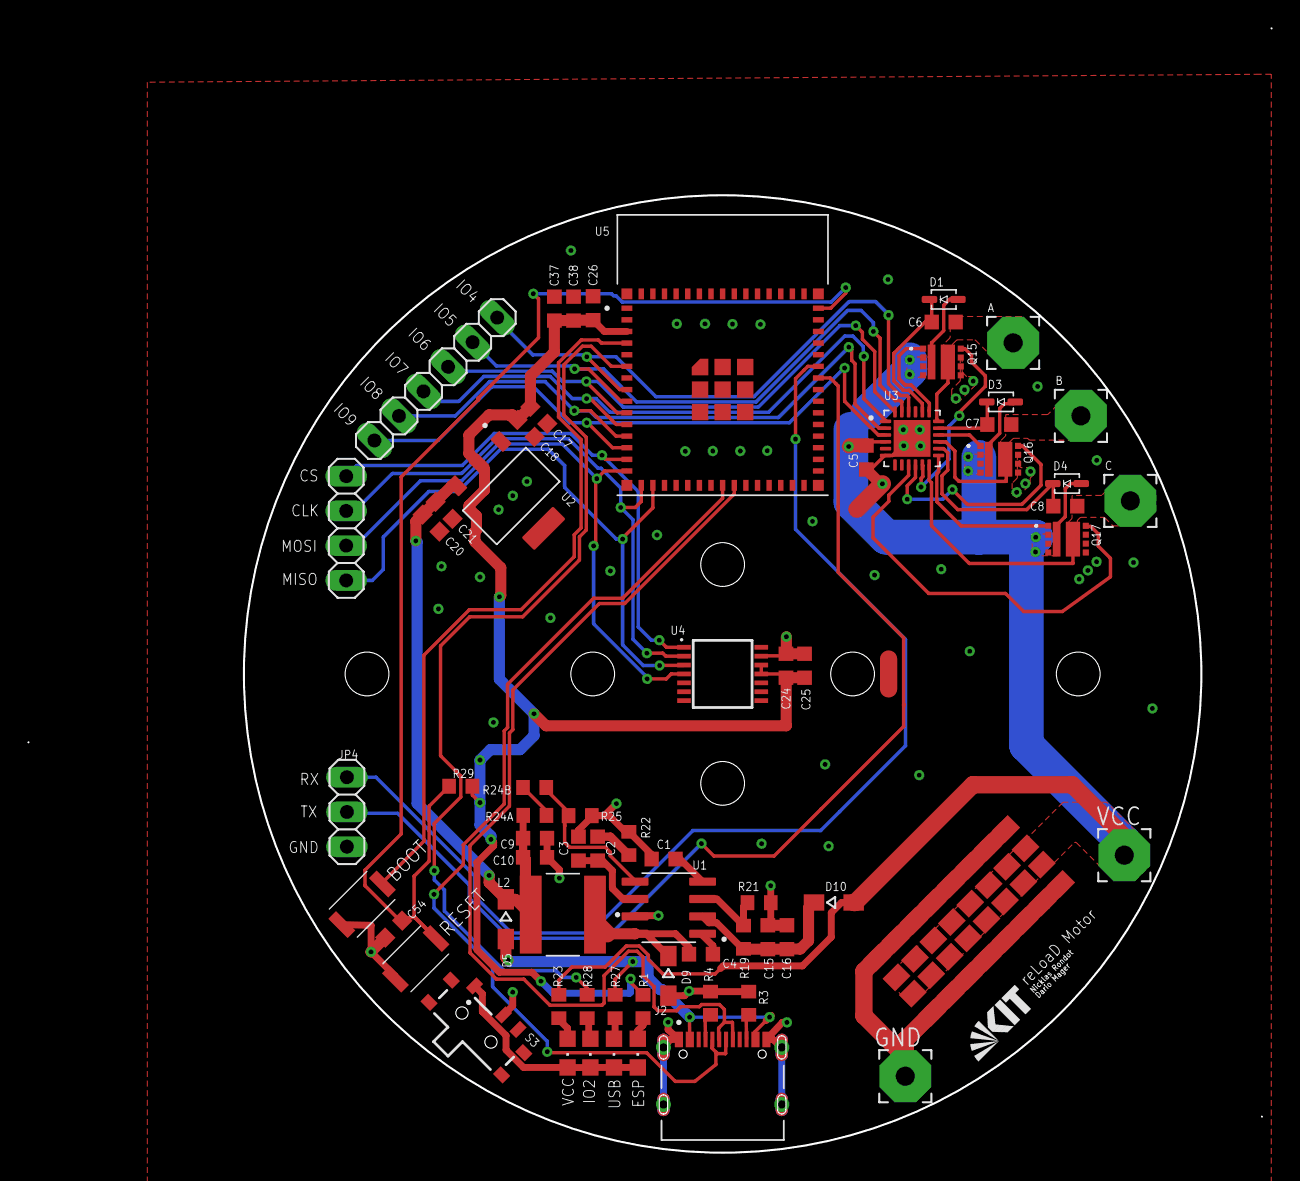
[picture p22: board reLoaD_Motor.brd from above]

Board: 2 copper layers, 70.0 x 70.0 mm, 82 parts (0 on the bottom side), 50 nets.

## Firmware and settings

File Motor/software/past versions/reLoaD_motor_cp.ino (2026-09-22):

#include <Arduino.h>
#include <SimpleFOC.h>

//BLE
#include <BLEDevice.h>
#include <BLEServer.h>
#include <BLEUtils.h>
#include <BLE2902.h>

BLEServer* pServer = NULL;
BLECharacteristic* cimoCharacteristic = NULL;
BLECharacteristic* comiCharacteristic = NULL;
bool deviceConnected = false;
bool oldDeviceConnected = false;
uint32_t value = 0;

float initial_zero_angle = 0;
float initial_offset = -0.545; // previously -0.225
float fw_dir_offset = 0;

int lastMode = 0;

#define SERVICE_UUID "19b10000-e8f2-537e-4f6c-d104768a1214"
#define CIMO_CHARACTERISTIC_UUID "19b10001-e8f2-537e-4f6c-d104768a1214"
#define COMI_CHARACTERISTIC_UUID "19b10002-e8f2-537e-4f6c-d104768a1214"


// MagneticSensorSPI(int cs, float _cpr, int _angle_register)
MagneticSensorSPI sensor = MagneticSensorSPI(10, 14, 0x3FFF);

// BLDC motor & driver instance
BLDCMotor motor = BLDCMotor(7);
BLDCDriver6PWM driver = BLDCDriver6PWM(4, 7, 5, 8, 6, 9);

// Commander interface constructor
Commander command = Commander(Serial);

void doTarget(char* cmd) {
  command.scalar(&motor.target, cmd);
}
void doMotor(char* cmd) {
  command.motor(&motor, cmd);
}


class MyServerCallbacks : public BLEServerCallbacks {
  void onConnect(BLEServer* pServer) {
    deviceConnected = true;
  };

  void onDisconnect(BLEServer* pServer) {
    deviceConnected = false;
  }
};



class MyCharacteristicCallbacks : public BLECharacteristicCallbacks {
  void onWrite(BLECharacteristic* comiCharacteristic) {
    std::string value = comiCharacteristic->getValue();
    if (value.length() > 0) {

      //Serial.print("Characteristic event, written: ");
      //Serial.println(value.c_str()); // Print the integer value

      std::string rpmVariable = "rpm ";
      std::string degVariable = "deg ";

      if (value.compare(0, rpmVariable.size(), rpmVariable) == 0) {
        value = value.substr(rpmVariable.size());
        int rpmValue = atoi(value.c_str());
        //Serial.println(rpmValue);
        float radValue = rpmValue / 9.5493;

        motor.controller = MotionControlType::velocity;
        motor.LPF_velocity.Tf = 0.005f;
        lastMode = 0;

        // Field weakening to achieve higher RPM
        if(rpmValue > 0){
          motor.zero_electric_angle = initial_zero_angle + initial_offset - fw_dir_offset;
        }
        if(rpmValue < 0){
          motor.zero_electric_angle = initial_zero_angle + initial_offset + fw_dir_offset;
        }

        if(rpmValue == 0){
          motor.zero_electric_angle = initial_zero_angle + initial_offset;
        }

        _delay(10);

        motor.move(radValue);
      }

      if (value.compare(0, degVariable.size(), degVariable) == 0) {
        value = value.substr(degVariable.size());
        int degValue = atoi(value.c_str());
        //Serial.println(degValue);
        float radValue = degValue / 57.2958;
        float angle = sensor.getAngle();
        if(lastMode == 0){
          float normalizedAngle = fmod(angle, 2 * PI);
          motor.controller = MotionControlType::angle;
          motor.LPF_velocity.Tf = 0.0005f; // added one zero
          motor.zero_electric_angle = initial_zero_angle + initial_offset;
          motor.sensor_offset = normalizedAngle - angle;  //+/- the expression depends on orientation of magnet
        }
        motor.move(radValue);
        lastMode = 1;
      }
    }
  }
};


void setup() {

  Serial.begin(115200);
  delay(100);

  //BLE------------
  // Create the BLE Device
  BLEDevice::init("Motor");

  // Create the BLE Server
  pServer = BLEDevice::createServer();
  pServer->setCallbacks(new MyServerCallbacks());

  // Create the BLE Service
  BLEService* pService = pServer->createService(SERVICE_UUID);

  // Create a BLE Characteristic
  cimoCharacteristic = pService->createCharacteristic(
    CIMO_CHARACTERISTIC_UUID,
    BLECharacteristic::PROPERTY_READ | BLECharacteristic::PROPERTY_WRITE | BLECharacteristic::PROPERTY_NOTIFY | BLECharacteristic::PROPERTY_INDICATE);

  // Create the ON button Characteristic
  comiCharacteristic = pService->createCharacteristic(
    COMI_CHARACTERISTIC_UUID,
    BLECharacteristic::PROPERTY_WRITE);

  // Register the callback for the ON button characteristic
  comiCharacteristic->setCallbacks(new MyCharacteristicCallbacks());

  // https://www.bluetooth.com/specifications/gatt/viewer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
  // Create a BLE Descriptor
  cimoCharacteristic->addDescriptor(new BLE2902());
  comiCharacteristic->addDescriptor(new BLE2902());

  // Start the service
  pService->start();

  // Start advertising
  BLEAdvertising* pAdvertising = BLEDevice::getAdvertising();
  pAdvertising->addServiceUUID(SERVICE_UUID);
  pAdvertising->setScanResponse(false);
  pAdvertising->setMinPreferred(0x0);  // set value to 0x00 to not advertise this parameter
  BLEDevice::startAdvertising();
  Serial.println("Waiting a client connection to notify...");

  //FOC----------

  sensor.init();
  motor.linkSensor(&sensor);

  // driver config
  driver.voltage_power_supply = 12;
  driver.init();


  // link the motor and the driver
  motor.linkDriver(&driver);

  // limiting motor movements
  //motor.phase_resistance = 0.251; // [Ohm]
  //motor.phase_inductance = 0.0001; // [Ohm]
  motor.foc_modulation = FOCModulationType::SpaceVectorPWM;
  //motor.current_limit = 10;   // [Amps] - if phase resistance defined
  // motor.voltage_limit = 1;   // [V] - if phase resistance not defined


  motor.KV_rating = 360;
  motor.phase_resistance = 0.24;

  motor.voltage_sensor_align = 0.6;

  // set torque mode to be used
  motor.torque_controller = TorqueControlType::voltage;  // ( default )
  // motor.torque_controller = TorqueControlType::dc_current;
  // motor.torque_controller = TorqueControlType::foc_current;

  // set motion control loop to be used
  // motor.controller = MotionControlType::torque; //      - torque control
  motor.controller = MotionControlType::velocity;  //    - velocity motion control
                                                   // motor.controller = MotionControlType::angle; //       - position/angle motion control
                                                   // motor.controller = MotionControlType::velocity_openloop; //    - velocity open-loop control
                                                   // motor.controller = MotionControlType::angle_openloop; //       - position open-loop control

  motor.PID_velocity.P = 1.5f; // Had it on 6 before for velocity tests but then at low speeds strong rumbling
  motor.PID_velocity.I = 0.05f;  // if higher, rumbling at high speeds will be stronger
  motor.PID_velocity.D = 0;
  motor.PID_velocity.output_ramp = 800;

  motor.LPF_velocity.Tf = 0.005f;

  motor.P_angle.output_ramp = 300;  // 900 no load
  motor.P_angle.P = 20;             //27.5 no load. Had it on 180 for position tests but may lead to rumbing. must fit to lpf filter 
  motor.P_angle.I = 0;
  motor.velocity_limit = 10;  // [rad/s]

  //motor.voltage_limit = 7;
  motor.current_limit = 5;

  motor.useMonitoring(Serial);

  // init motor hardware
  motor.init();


  // align sensor and start FOC
  motor.initFOC();

  _delay(100);

  initial_zero_angle = motor.zero_electric_angle;
  motor.zero_electric_angle += initial_offset;

  _delay(100);

  // set the initial motor target
  motor.target = 0;  // unit depends on control mode

  // add target command T
  command.add('T', doTarget, "target angle");
  command.add('M', doMotor, "my motor motion");
  _delay(100);
}

void loop() {

  motor.loopFOC();
  motor.move();
  motor.monitor();
  command.run();

  // disconnecting
  if (!deviceConnected && oldDeviceConnected) {
    Serial.println("Device disconnected.");
    delay(500);                   // give the bluetooth stack the chance to get things ready
    pServer->startAdvertising();  // restart advertising
    Serial.println("Start advertising");
    oldDeviceConnected = deviceConnected;
  }
  // connecting
  if (deviceConnected && !oldDeviceConnected) {
    // do stuff here on connecting
    oldDeviceConnected = deviceConnected;
    Serial.println("Device Connected");
  }
}

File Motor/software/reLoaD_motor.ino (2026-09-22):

#include <Arduino.h>
#include <SimpleFOC.h>

//BLE
#include <BLEDevice.h>
#include <BLEServer.h>
#include <BLEUtils.h>
#include <BLE2902.h>

BLEServer* pServer = NULL;
BLECharacteristic* cimoCharacteristic = NULL;
BLECharacteristic* comiCharacteristic = NULL;
bool deviceConnected = false;
bool oldDeviceConnected = false;

int lastMode = 0;

#define SERVICE_UUID "19b10000-e8f2-537e-4f6c-d104768a1214"
#define CIMO_CHARACTERISTIC_UUID "19b10001-e8f2-537e-4f6c-d104768a1214"
#define COMI_CHARACTERISTIC_UUID "19b10002-e8f2-537e-4f6c-d104768a1214"

MagneticSensorSPI sensor = MagneticSensorSPI(10, 14, 0x3FFF);
BLDCMotor motor = BLDCMotor(7);
BLDCDriver6PWM driver = BLDCDriver6PWM(4, 7, 5, 8, 6, 9);
Commander command = Commander(Serial);

void doTarget(char* cmd) { command.scalar(&motor.target, cmd); }
void doMotor(char* cmd) { command.motor(&motor, cmd); }

class MyServerCallbacks : public BLEServerCallbacks {
  void onConnect(BLEServer* pServer) { deviceConnected = true; };
  void onDisconnect(BLEServer* pServer) { deviceConnected = false; }
};

class MyCharacteristicCallbacks : public BLECharacteristicCallbacks {
  void onWrite(BLECharacteristic* comiCharacteristic) {
    std::string value = comiCharacteristic->getValue();
    if (value.length() > 0) {
      
      std::string rpmVariable = "rpm ";
      std::string degVariable = "deg ";

      // --- RPM MODE ---
      if (value.compare(0, rpmVariable.size(), rpmVariable) == 0) {
        value = value.substr(rpmVariable.size());
        int rpmValue = atoi(value.c_str());
        float radValue = rpmValue / 9.5493;

        if(motor.controller != MotionControlType::velocity){
             motor.controller = MotionControlType::velocity;
             motor.LPF_velocity.Tf = 0.005f;
             lastMode = 0;
        }
        motor.target = radValue;
      }

      // --- POSITION MODE ---
      if (value.compare(0, degVariable.size(), degVariable) == 0) {
        value = value.substr(degVariable.size());
        int degValue = atoi(value.c_str());
        float targetRad = degValue / 57.2958;
        
        if(lastMode == 0){
            motor.controller = MotionControlType::angle;
            motor.LPF_velocity.Tf = 0.0005f;
            lastMode = 1;
        }

        // --- SHORTEST PATH LOGIC (The Fix) ---
        // This replicates your old behavior (nearest angle) without breaking commutation.
        
        // 1. Normalize target to 0-2PI
        float target_mod = fmod(targetRad, _2PI);
        if (target_mod < 0) target_mod += _2PI;

        // 2. Normalize current motor angle to 0-2PI
        float current_mod = fmod(motor.shaft_angle, _2PI);
        if (current_mod < 0) current_mod += _2PI;

        // 3. Calculate the shortest difference
        float error = target_mod - current_mod;
        
        // If difference is > 180 deg, go the other way
        if (error > PI) error -= _2PI;
        if (error < -PI) error += _2PI;

        // 4. Apply to the real absolute angle
        motor.target = motor.shaft_angle + error;
      }
    }
  }
};

void setup() {
  Serial.begin(115200);

  // BLE Setup
  BLEDevice::init("Motor");
  pServer = BLEDevice::createServer();
  pServer->setCallbacks(new MyServerCallbacks());
  BLEService* pService = pServer->createService(SERVICE_UUID);
  cimoCharacteristic = pService->createCharacteristic(
    CIMO_CHARACTERISTIC_UUID,
    BLECharacteristic::PROPERTY_READ | BLECharacteristic::PROPERTY_WRITE | BLECharacteristic::PROPERTY_NOTIFY | BLECharacteristic::PROPERTY_INDICATE);
  comiCharacteristic = pService->createCharacteristic(
    COMI_CHARACTERISTIC_UUID,
    BLECharacteristic::PROPERTY_WRITE);
  comiCharacteristic->setCallbacks(new MyCharacteristicCallbacks());
  cimoCharacteristic->addDescriptor(new BLE2902());
  comiCharacteristic->addDescriptor(new BLE2902());
  pService->start();
  BLEAdvertising* pAdvertising = BLEDevice::getAdvertising();
  pAdvertising->addServiceUUID(SERVICE_UUID);
  pAdvertising->setScanResponse(false);
  pAdvertising->setMinPreferred(0x0);
  BLEDevice::startAdvertising();

  // FOC Setup
  sensor.init();
  motor.linkSensor(&sensor);

  driver.voltage_power_supply = 12;
  driver.dead_zone = 0.02f; // Keeps MOSFETs safe
  driver.init();
  motor.linkDriver(&driver);

  motor.foc_modulation = FOCModulationType::SpaceVectorPWM;
  motor.KV_rating = 750; 
  
  motor.voltage_limit = 4.0;
  // Correct Resistance
  //motor.phase_resistance = 0.1; 

  motor.voltage_sensor_align = 0.65; 
  motor.torque_controller = TorqueControlType::voltage; 
  motor.controller = MotionControlType::velocity;

  // PID Velocity
  motor.PID_velocity.P = 0.0005f; 
  motor.PID_velocity.I = 0.005f; 
  motor.PID_velocity.D = 0;
  motor.PID_velocity.output_ramp = 10;
  motor.LPF_velocity.Tf = 0.01f; 

  // PID Angle
  motor.P_angle.P = 10; // Lower P for 0.1ohm motor
  motor.P_angle.I = 0;
  motor.P_angle.output_ramp = 300;

  // Limits
  motor.current_limit = 3.0f; 
  motor.velocity_limit = 10; 


  motor.monitor_downsample = 500;
  motor.useMonitoring(Serial);
  motor.init();
  motor.initFOC();
  
  motor.target = 0;

  command.add('T', doTarget, "target angle");
  command.add('M', doMotor, "my motor motion");
}

void loop() {
  motor.loopFOC();
  motor.move();
  //motor.monitor();
  command.run();

  if (!deviceConnected && oldDeviceConnected) {
    delay(500);
    pServer->startAdvertising();
    oldDeviceConnected = deviceConnected;
  }
  if (deviceConnected && !oldDeviceConnected) {
    oldDeviceConnected = deviceConnected;
  }
}

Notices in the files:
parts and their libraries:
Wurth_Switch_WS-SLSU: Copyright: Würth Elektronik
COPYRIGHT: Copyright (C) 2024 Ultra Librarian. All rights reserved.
